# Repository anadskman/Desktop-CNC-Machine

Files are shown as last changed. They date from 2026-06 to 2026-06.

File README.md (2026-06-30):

# Desktop CNC Machine

A custom-designed desktop CNC machine built from scratch in Fusion 360. The machine is designed for cutting wood, foam, and other lightweight materials while remaining affordable and easy to build.

## Overview

This project started as a belt-driven CNC but was later redesigned to use leadscrews on all axes for improved accuracy and simpler mechanics.

The machine uses:

* 3 Axis Motion (X, Y, Z)
* Arduino Uno + CNC Shield
* GRBL Firmware
* NEMA 17 Stepper Motors
* T8 Leadscrews
* 2020 Aluminium Extrusion Frame
* 3D Printed Components

## Specifications

| Specification | Value |
| --- | --- |
| Working Area  | ~200mm × 200mm |
| Axes | 3 |
| Motion System | T8 Leadscrews |
| Guide System  | 8mm Smooth Rods + SCS8UU Bearings |
| Controller | Arduino Uno |
| Firmware | GRBL |
| Frame | 2020 Aluminium Extrusion |
| Spindle | 775 DC Motor |

## Features

* Fully custom CAD design
* Modular axis design
* Leadscrew-driven motion
* Aluminium extrusion frame
* 6 Endstop support
* GRBL compatible
* 3D printable components
* Standard off-the-shelf hardware

## Design Process

### Initial Concept

The original design used:

* GT2 Belts
* GT2 Pulleys
* LM8UU Bearings

After modelling the system in Fusion 360, the design was changed to use leadscrews for improved accuracy and simpler assembly.

### Y-Axis

The Y-axis was the first axis designed.

The final version includes:

* Two 8mm smooth rods
* One T8 leadscrew
* SCS8UU bearing blocks
* 2020 aluminium extrusion base

The frame was redesigned to use four aluminium extrusions with custom 3D printed mounting components.

### X-Axis

The X-axis was redesigned to improve strength and simplify assembly.

Changes included:

* Stronger side supports
* 70° angled reinforcement
* Direct Z-axis mounting points
* Improved carriage design

### Z-Axis

The Z-axis was completely redesigned.

Features include:

* Direct mounting to the X-axis carriage
* Dual guide rods
* Leadscrew-driven motion
* Custom spindle clamp

The spindle mount uses a clamping system with screws and includes a bottom support to prevent the spindle from falling through.

## Electronics

### Components

* Arduino Uno
* CNC Shield
* 3× Stepper Drivers
* 3× NEMA 17 Motors
* 6× Endstops
* Spindle Driver
* 775 Spindle Motor

### Software

Firmware:

* GRBL

Control Software:

* Universal G-Code Sender (UGS)

UGS will be used for:

* Machine control
* Sending G-code
* GRBL configuration
* Testing and calibration

## CAD Improvements

Several improvements were made throughout development:

* Fillets for improved looks
* Standardised component sizes
* Buyable rod and leadscrew lengths
* Organised Fusion component structure
* Motion simulation using joints

## Bill of Materials

|Name|Purpose |Quantity|Total Cost (USD) |Link |Distributor|
|----|---|---|---|---|---|
|DC Motor RS775 Spindle motor 12V with driver|router |1 |41.09 |https://www.aliexpress.com/item/1005005719789481.html?pdp_ext_f=%7B"order"%3A"77"%2C"eval"%3A"1"%2C"fromPage"%3A"search"%7D |Aliexpress |
|t8 leadscrew nut 4pc|connects carriage to leadscrew|1 |5.62 |https://www.aliexpress.com/item/1005007188421437.html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"order"%3A"180"%2C"spu_best_type"%3A"price"%2C"eval"%3A"1"%2C"fromPage"%3A"search"%7D&search_p4p_id=202606010645565259910943250180003872754_1 |aliexpress |
|5pc endstops|stops the carriage from moving too far|1 |4.77 |https://www.aliexpress.com/item/1005008178660096.html?pdp_ext_f=%7B"order"%3A"125"%2C"eval"%3A"1"%2C"fromPage"%3A"search"%7D |Aliexpress |
|t8 Leadscrews 250mm|Leadscrews |1 |11.82 |https://www.aliexpress.com/item/1005010726899970.html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 |Aliexpress |
|t8 Leadscrew 100mm|Leadscrew |1 |3.70 |https://www.aliexpress.com/item/1005010726899970.html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 |Aliexpress |
|Leadscrew Clamps|connects the motor to the leadscrews|1 |7.93 |https://www.aliexpress.com/item/1005007820393080.html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 |Aliexpress |
|Linear Bearings|Moves long the smooth rods |1 |6.45 |https://www.aliexpress.com/item/1005004108098706.html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 |Aliexpress |
|8mm Ball Bearings 10pc|Lets the leadscrews rotate |1 |2.11 |https://www.aliexpress.com/item/1005011548989882.html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 |Aliexpress |
|Stepper Motor/Shield Kit|Moves the actual axis carriage|1 |59.54 |https://www.aliexpress.com/item/1005004698792964.html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"order"%3A"354"%2C"eval"%3A"1"%2C"sceneId"%3A"30050"%2C"fromPage"%3A"recommend"%7D|Aliexpress |
|150mm/8mm Smooth Rods|linear shafts for each axis  |1 |9.28 |https://www.aliexpress.com/item/1005006293171727.html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 |Aliexpress |
|300mm/8mm smooth rod|linear shafts for each axis  |1 |32.52 |https://www.aliexpress.com/item/1005006293171727.html?mp=1&pdp_ext_f=%7B"cart2PdpParams"%3A%7B"pdpBusinessMode"%3A"retail"%7D%7D |Aliexpress |
|2020 Extrusion 4pc|To hold the base |1 |19.05 |https://www.aliexpress.com/item/1005003299342998.html?pdp_ext_f=%7B"order"%3A"405"%2C"eval"%3A"1"%2C"fromPage"%3A"search"%7D |Aliexpress |

Estimated cost:
**$180 - $210 USD**

## Project Goals

* Design a CNC machine from scratch
* Learn CNC design principles
* Learn motion control systems
* Create a functional desktop CNC
* Successfully cut wood and foam
* Produce simple engraved projects

## Gallery

CNC Machine


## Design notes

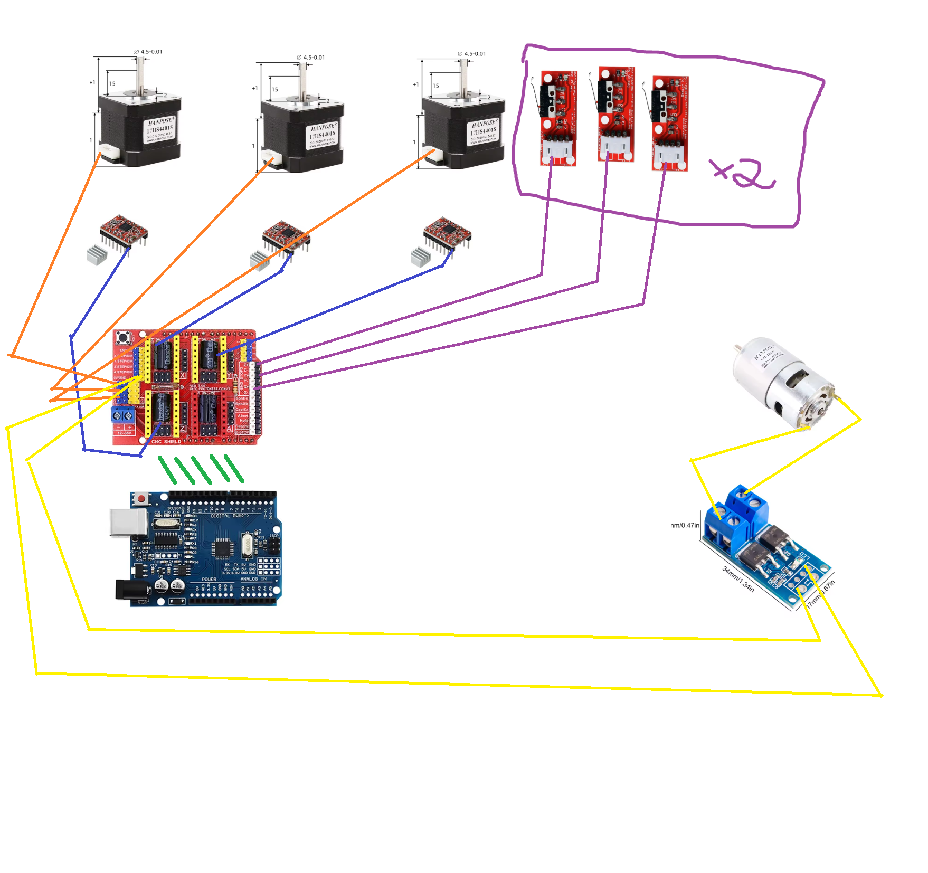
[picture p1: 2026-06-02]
Schematic/CNC Machine.png

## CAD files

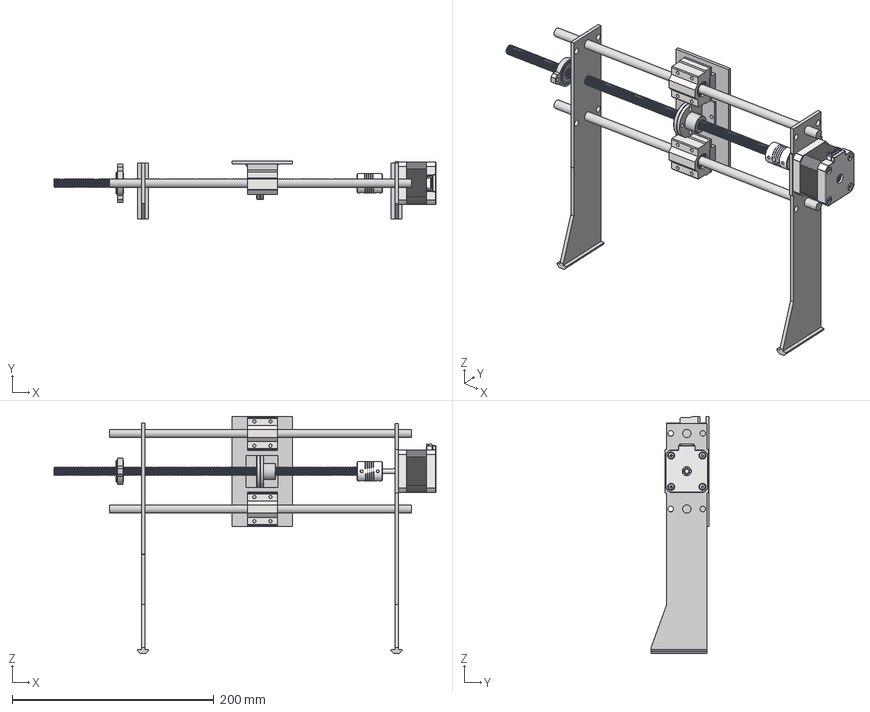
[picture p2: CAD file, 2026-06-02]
CAD/X-Axis Assembled.step
379.2 x 57.5 x 235.4 mm
rear end cap
rear bearing
connector
shaft
stator
front end cap
front bearing
M3x10-Screw x 4
Flexible Shaft Coupler 5x8mm
OUTER RACE
INNER RACE
RETAINER
BALL x 8
COVER x 2
BrassNut
SCS8UU x 2

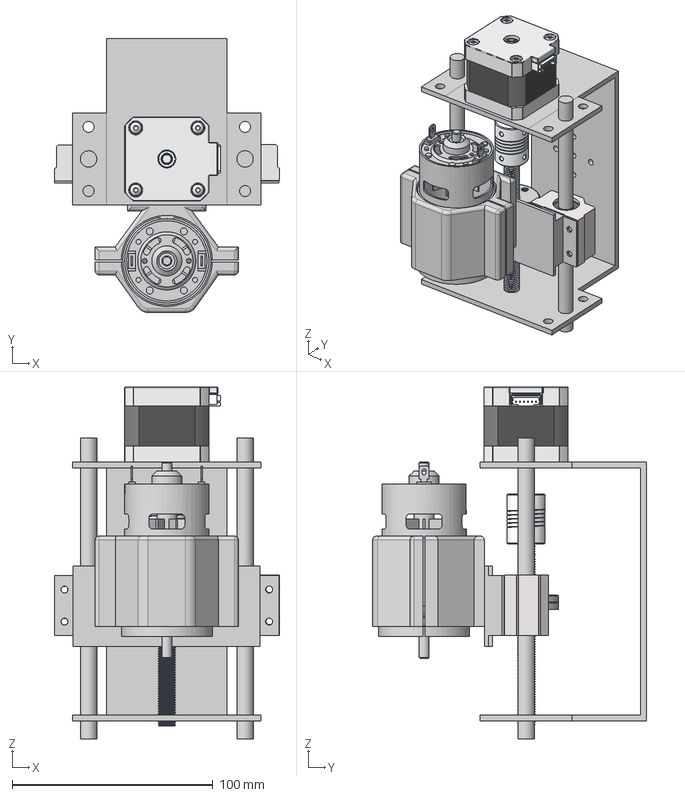
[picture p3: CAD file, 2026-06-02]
CAD/Z-Axis Assembled.step
112.2 x 136.5 x 175.5 mm
rear end cap
rear bearing
connector
shaft
stator
front end cap
front bearing
M3x10-Screw x 4
Flexible Shaft Coupler 5x8mm
BrassNut
SCS8UU x 2
МОТОР 775

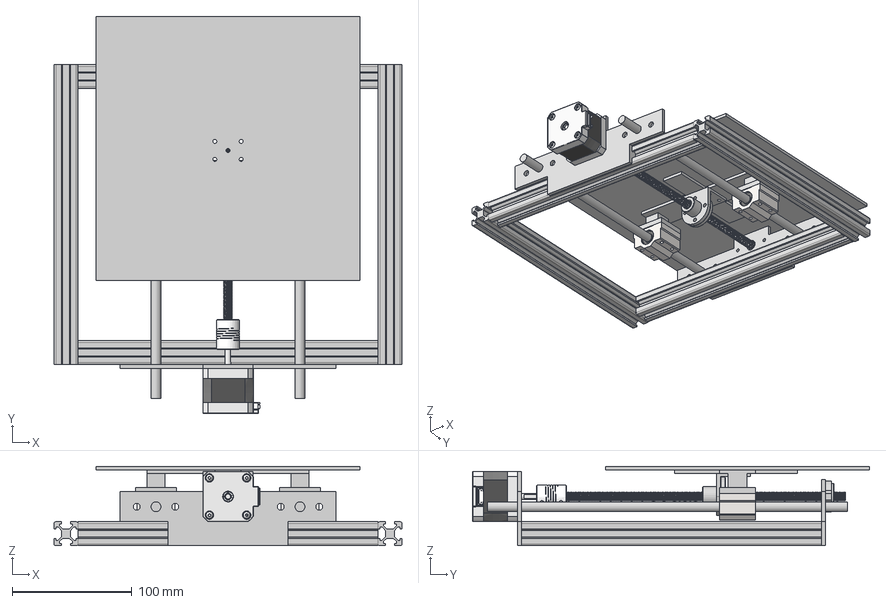
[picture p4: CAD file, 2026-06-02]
CAD/Y-Axis Assembled.step
290.0 x 330.9 x 66.2 mm
rear end cap
rear bearing
connector
shaft
stator
front end cap
front bearing
M3x10-Screw x 4
Flexible Shaft Coupler 5x8mm
OUTER RACE
INNER RACE
RETAINER
BALL x 8
COVER x 2
BrassNut
SCS8UU x 2

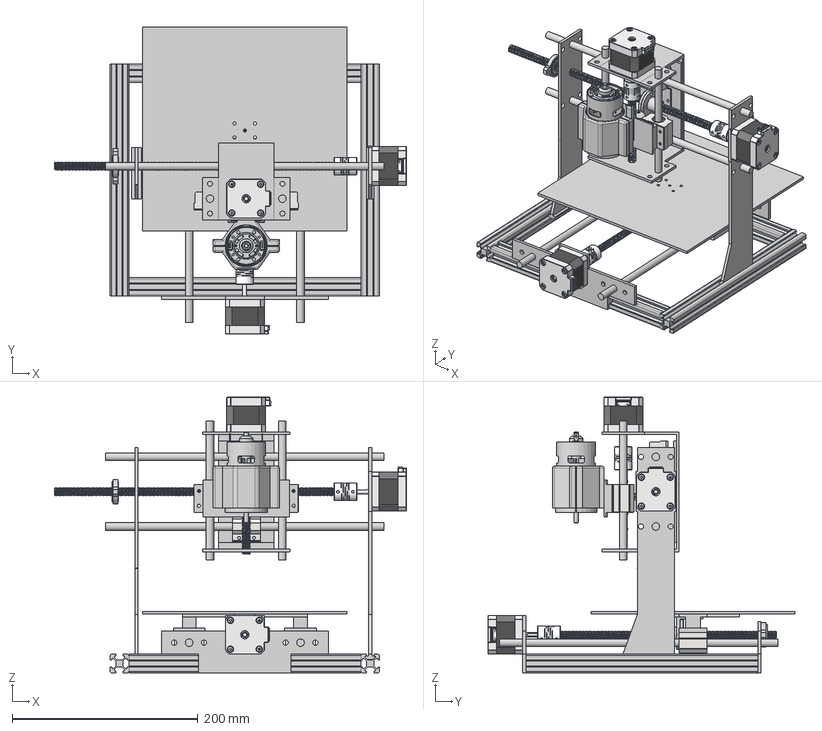
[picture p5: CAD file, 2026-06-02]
CAD/Desktop CNC Machine Full Assembly.step
379.2 x 330.9 x 296.9 mm
rear end cap x 3
rear bearing x 3
connector x 3
shaft x 3
stator x 3
front end cap x 3
front bearing x 3
M3x10-Screw x 12
Flexible Shaft Coupler 5x8mm x 3
OUTER RACE x 2
INNER RACE x 2
RETAINER x 2
BALL x 16
COVER x 4
BrassNut x 3
SCS8UU x 6
МОТОР 775

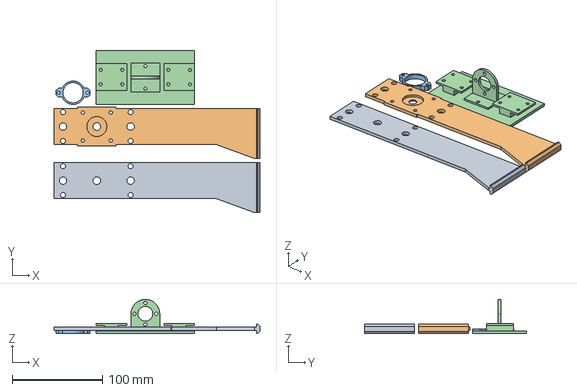
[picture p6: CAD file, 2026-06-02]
CAD/X-Axis Printable.step
228.5 x 180.0 x 38.0 mm
Carriage (1)

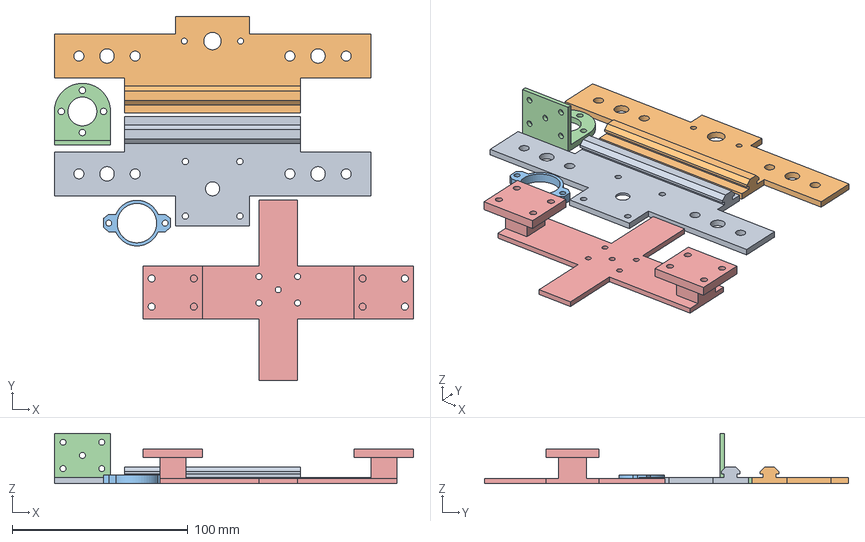
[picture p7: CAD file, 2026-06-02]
CAD/Y-Axis Printable.step
204.4 x 207.0 x 28.5 mm
Frame
Carriage

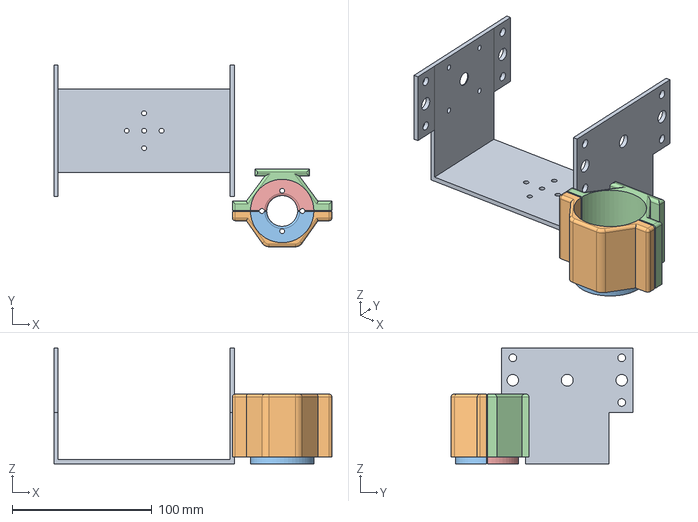
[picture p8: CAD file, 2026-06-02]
CAD/Z-Axis Printable.step
199.2 x 130.2 x 83.0 mm
Frame
Carriage

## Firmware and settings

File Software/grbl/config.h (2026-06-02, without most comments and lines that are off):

#define config_h
#include "grbl.h" // For Arduino IDE compatibility.
#define DEFAULTS_GENERIC
#define CPU_MAP_ATMEGA328P // Arduino Uno CPU
#define BAUD_RATE 115200
#define CMD_RESET 0x18 // ctrl-x.
#define CMD_STATUS_REPORT '?'
#define CMD_CYCLE_START '~'
#define CMD_FEED_HOLD '!'
#define CMD_SAFETY_DOOR 0x84
#define CMD_JOG_CANCEL  0x85
#define CMD_DEBUG_REPORT 0x86 // Only when DEBUG enabled, sends debug report in '{}' braces.
#define CMD_FEED_OVR_RESET 0x90         // Restores feed override value to 100%.
#define CMD_FEED_OVR_COARSE_PLUS 0x91
#define CMD_FEED_OVR_COARSE_MINUS 0x92
#define CMD_FEED_OVR_FINE_PLUS  0x93
#define CMD_FEED_OVR_FINE_MINUS  0x94
#define CMD_RAPID_OVR_RESET 0x95        // Restores rapid override value to 100%.
#define CMD_RAPID_OVR_MEDIUM 0x96
#define CMD_RAPID_OVR_LOW 0x97
#define CMD_SPINDLE_OVR_RESET 0x99      // Restores spindle override value to 100%.
#define CMD_SPINDLE_OVR_COARSE_PLUS 0x9A
#define CMD_SPINDLE_OVR_COARSE_MINUS 0x9B
#define CMD_SPINDLE_OVR_FINE_PLUS 0x9C
#define CMD_SPINDLE_OVR_FINE_MINUS 0x9D
#define CMD_SPINDLE_OVR_STOP 0x9E
#define CMD_COOLANT_FLOOD_OVR_TOGGLE 0xA0
#define CMD_COOLANT_MIST_OVR_TOGGLE 0xA1
#define HOMING_INIT_LOCK // Comment to disable
#define HOMING_CYCLE_0 (1<<Z_AXIS)                // REQUIRED: First move Z to clear workspace.
#define HOMING_CYCLE_1 ((1<<X_AXIS)|(1<<Y_AXIS))  // OPTIONAL: Then move X,Y at the same time.
#define N_HOMING_LOCATE_CYCLE 1 // Integer (1-128)
#define N_STARTUP_LINE 2 // Integer (1-2)
#define N_DECIMAL_COORDVALUE_INCH 4 // Coordinate or position value in inches
#define N_DECIMAL_COORDVALUE_MM   3 // Coordinate or position value in mm
#define N_DECIMAL_RATEVALUE_INCH  1 // Rate or velocity value in in/min
#define N_DECIMAL_RATEVALUE_MM    0 // Rate or velocity value in mm/min
#define N_DECIMAL_SETTINGVALUE    3 // Decimals for floating point setting values
#define N_DECIMAL_RPMVALUE        0 // RPM value in rotations per min.
#define MESSAGE_PROBE_COORDINATES // Enabled by default. Comment to disable.
#define SAFETY_DOOR_SPINDLE_DELAY 4.0 // Float (seconds)
#define SAFETY_DOOR_COOLANT_DELAY 1.0 // Float (seconds)
#define CHECK_LIMITS_AT_INIT
#define DEFAULT_FEED_OVERRIDE           100 // 100%. Don't change this value.
#define MAX_FEED_RATE_OVERRIDE          200 // Percent of programmed feed rate (100-255). Usually 120% or 200%
#define MIN_FEED_RATE_OVERRIDE           10 // Percent of programmed feed rate (1-100). Usually 50% or 1%
#define FEED_OVERRIDE_COARSE_INCREMENT   10 // (1-99). Usually 10%.
#define FEED_OVERRIDE_FINE_INCREMENT      1 // (1-99). Usually 1%.
#define DEFAULT_RAPID_OVERRIDE  100 // 100%. Don't change this value.
#define RAPID_OVERRIDE_MEDIUM    50 // Percent of rapid (1-99). Usually 50%.
#define RAPID_OVERRIDE_LOW       25 // Percent of rapid (1-99). Usually 25%.
#define DEFAULT_SPINDLE_SPEED_OVERRIDE    100 // 100%. Don't change this value.
#define MAX_SPINDLE_SPEED_OVERRIDE        200 // Percent of programmed spindle speed (100-255). Usually 200%.
#define MIN_SPINDLE_SPEED_OVERRIDE         10 // Percent of programmed spindle speed (1-100). Usually 10%.
#define SPINDLE_OVERRIDE_COARSE_INCREMENT  10 // (1-99). Usually 10%.
#define SPINDLE_OVERRIDE_FINE_INCREMENT     1 // (1-99). Usually 1%.
#define RESTORE_OVERRIDES_AFTER_PROGRAM_END // Default enabled. Comment to disable.
#define REPORT_FIELD_BUFFER_STATE // Default enabled. Comment to disable.
#define REPORT_FIELD_PIN_STATE // Default enabled. Comment to disable.
#define REPORT_FIELD_CURRENT_FEED_SPEED // Default enabled. Comment to disable.
#define REPORT_FIELD_WORK_COORD_OFFSET // Default enabled. Comment to disable.
#define REPORT_FIELD_OVERRIDES // Default enabled. Comment to disable.
#define REPORT_FIELD_LINE_NUMBERS // Default enabled. Comment to disable.
#define REPORT_OVR_REFRESH_BUSY_COUNT 20  // (1-255)
#define REPORT_OVR_REFRESH_IDLE_COUNT 10  // (1-255) Must be less than or equal to the busy count
#define REPORT_WCO_REFRESH_BUSY_COUNT 30  // (2-255)
#define REPORT_WCO_REFRESH_IDLE_COUNT 10  // (2-255) Must be less than or equal to the busy count
#define ACCELERATION_TICKS_PER_SECOND 100
#define ADAPTIVE_MULTI_AXIS_STEP_SMOOTHING  // Default enabled. Comment to disable.
#define TOOL_LENGTH_OFFSET_AXIS Z_AXIS // Default z-axis. Valid values are X_AXIS, Y_AXIS, or Z_AXIS.
#define VARIABLE_SPINDLE // Default enabled. Comment to disable.
#define MINIMUM_JUNCTION_SPEED 0.0 // (mm/min)
#define MINIMUM_FEED_RATE 1.0 // (mm/min)
#define N_ARC_CORRECTION 12 // Integer (1-255)
#define ARC_ANGULAR_TRAVEL_EPSILON 5E-7 // Float (radians)
#define DWELL_TIME_STEP 50 // Integer (1-255) (milliseconds)
#define ENABLE_RESTORE_EEPROM_WIPE_ALL         // '$RST=*' Default enabled. Comment to disable.
#define ENABLE_RESTORE_EEPROM_DEFAULT_SETTINGS // '$RST=$' Default enabled. Comment to disable.
#define ENABLE_RESTORE_EEPROM_CLEAR_PARAMETERS // '$RST=#' Default enabled. Comment to disable.
#define ENABLE_BUILD_INFO_WRITE_COMMAND // '$I=' Default enabled. Comment to disable.
#define FORCE_BUFFER_SYNC_DURING_EEPROM_WRITE // Default enabled. Comment to disable.
#define FORCE_BUFFER_SYNC_DURING_WCO_CHANGE // Default enabled. Comment to disable.
#define PARKING_AXIS Z_AXIS // Define which axis that performs the parking motion
#define PARKING_TARGET -5.0 // Parking axis target. In mm, as machine coordinate [-max_travel,0].
#define PARKING_RATE 500.0 // Parking fast rate after pull-out in mm/min.
#define PARKING_PULLOUT_RATE 100.0 // Pull-out/plunge slow feed rate in mm/min.
#define PARKING_PULLOUT_INCREMENT 5.0 // Spindle pull-out and plunge distance in mm. Incremental distance.
#define DISABLE_LASER_DURING_HOLD // Default enabled. Comment to disable.
#define N_PIECES 4  // Integer (1-4). Number of piecewise lines used in script solution.
#define RPM_MAX  11686.4  // Max RPM of model. $30 > RPM_MAX will be limited to RPM_MAX.
#define RPM_MIN  202.5    // Min RPM of model. $31 < RPM_MIN will be limited to RPM_MIN.
#define RPM_POINT12  6145.4  // Used N_PIECES >=2. Junction point between lines 1 and 2.
#define RPM_POINT23  9627.8  // Used N_PIECES >=3. Junction point between lines 2 and 3.
#define RPM_POINT34  10813.9 // Used N_PIECES = 4. Junction point between lines 3 and 4.
#define RPM_LINE_A1  3.197101e-03  // Used N_PIECES >=1. A and B constants of line 1.
#define RPM_LINE_B1  -3.526076e-1
#define RPM_LINE_A2  1.722950e-2   // Used N_PIECES >=2. A and B constants of line 2.
#define RPM_LINE_B2  8.588176e+01
#define RPM_LINE_A3  5.901518e-02  // Used N_PIECES >=3. A and B constants of line 3.
#define RPM_LINE_B3  4.881851e+02
#define RPM_LINE_A4  1.203413e-01  // Used N_PIECES = 4. A and B constants of line 4.
#define RPM_LINE_B4  1.151360e+03
#define DUAL_AXIS_SELECT  X_AXIS  // Must be either X_AXIS or Y_AXIS
#define DUAL_AXIS_HOMING_FAIL_AXIS_LENGTH_PERCENT  5.0  // Float (percent)
#define DUAL_AXIS_HOMING_FAIL_DISTANCE_MAX  25.0  // Float (mm)
#define DUAL_AXIS_HOMING_FAIL_DISTANCE_MIN  2.5  // Float (mm)
#define DUAL_AXIS_CONFIG_PROTONEER_V3_51    // Uncomment to select. Comment other configs.

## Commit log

2026-06-20 Revise Bill of Materials with component details
    Updated the Bill of Materials section with detailed component information and links.
2026-06-30 Revise Bill of Materials in README
    Updated Bill of Materials section with new items and costs.
2026-06-30 Update Mini Desktop CNC-bom.csv
    [Mini Desktop CNC-bom.csv]

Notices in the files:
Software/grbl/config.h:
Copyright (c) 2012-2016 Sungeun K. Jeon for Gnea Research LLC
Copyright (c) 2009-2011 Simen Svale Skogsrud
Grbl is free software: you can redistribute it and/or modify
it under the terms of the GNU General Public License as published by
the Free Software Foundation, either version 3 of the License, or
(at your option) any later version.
